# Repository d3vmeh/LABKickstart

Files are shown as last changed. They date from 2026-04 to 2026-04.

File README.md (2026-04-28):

# LABKickstart

> An open, modular, IoT-enabled physics lab toolkit.
> 🥇 **1st place overall — IDEA Hacks 2026**

LABKickstart turns a laptop and a few $10 ESP32 boards into a complete physics
lab data-acquisition system. Each module reads one sensor and broadcasts over
Bluetooth LE; a Python web dashboard receives the streams, runs experiment-
specific derivations, plots live data, writes clean CSVs, and (optionally)
uses an LLM to convert teachers' existing lab handouts into student-facing
setup guides.

**No proprietary base station. No proprietary file format. No vendor lock-in.**

---

## Why

Incumbents have controlled high school physics for years. A $450 base station
before you buy a single sensor; locked connectors; locked file formats. A
district that has spent $30k on one vendor has to keep buying that vendor —
every locked connector is a moat.

A full LABKickstart kit costs less than one typical base station and unlocks
20+ standard physics experiments — Hooke's law, Atwood machines, projectile
motion, free fall, pendulums, collisions, friction, buoyancy.

Every line of firmware, every Python module, every CAD file is open source.
A teacher who has spent twenty years using existing tools can fork an experiment, modify
it for their classroom, and share it with the teacher next door — in twenty
minutes.

---

## Open hardware

All mechanical designs live in OnShape and are publicly viewable:

**🔗 [LABKickstart CAD on OnShape](https://cad.onshape.com/documents/6798fb3b1ef260424d103dd4/w/9adcb538dd3efbe956fa17f1/e/e2a2e2dccae245fef01fc912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)**

Includes the photogate housings, IMU mounts, the ToF stand, and the modular
mounting rail that lets students reconfigure setups between experiments.
Fork the workspace, modify, export STLs, print, run.

Firmware (Arduino sketches per module) lives in [`firmware/`](firmware/).

---

## Architecture

```
┌─────────────────┐  BLE notify   ┌──────────────────┐    WebSocket   ┌──────────────┐
│ ESP32 module(s) │ ────────────> │ Python Hub       │ ─────────────> │ uPlot charts │
│  (one sensor    │   GATT char   │  · BLE manager   │                │ (vanilla JS) │
│   per board)    │               │  · Kit derive    │ ─── CSV ────>  │              │
└─────────────────┘               │  · Run + trigger │                │              │
                                  │  · LLM (teacher) │                │              │
                                  └──────────────────┘                └──────────────┘
```

- **Modules** ([`firmware/`](firmware/)) — Arduino sketches per sensor (photogate, IMU, ToF).
- **BLE manager** (`src/labkickstart/ble_manager.py`) — profile registry,
  auto-discovery of NOTIFY characteristics, per-connection stateful decoders.
- **Hub** (`src/labkickstart/app.py`) — single asyncio event loop. Fans every
  decoded sample to (1) the active run's CSV writer, (2) all WebSocket
  subscribers, and (3) the active kit's `derive()` function, which can emit
  additional physics-quantity samples back into the same fan-out.
- **Kits** (`src/labkickstart/kits.py`) — one Python class per experiment.
  Each declares `info`, `configure(params)`, `derive(sample)`, and the BLE
  modules it requires. Adding an experiment = adding one class.
- **Lab-guide LLM** (`src/labkickstart/lab_guides.py`) — gpt-4o-mini with
  schema-constrained output. Two flows: kit recommender (PDF → ranked kits)
  and student-facing setup guide.
- **Quicklook** (`src/labkickstart/quicklook.py`) — per-channel summary stats
  (count, mean, median, p5, p95, σ, σ/√N) computed from any run's CSV.
- **Frontend** (`src/labkickstart/static/`) — vanilla JS, uPlot, no build
  step. Per-device chart cards keep different sensor scales from crushing
  each other on a shared y-axis.

---

## Quickstart

Runs on macOS or a Raspberry Pi 4 (any host with Bluetooth and Python 3.11+).

```bash
# 1. Clone + install
git clone https://github.com/d3vmeh/LABKickstart
cd LABKickstart
python3 -m venv .venv
.venv/bin/pip install -r requirements.txt

# 2. (optional) AI features
echo "OPENAI_API_KEY=sk-..." > .env

# 3. Launch the dashboard
./dev.sh
# -> open http://localhost:8000
```

`dev.sh` injects `src/` onto `PYTHONPATH` and starts uvicorn with
`--reload`. Override host/port via env:

```bash
HOST=127.0.0.1 PORT=8001 ./dev.sh
```

### No hardware? Use a mock source

Set `LK_SENSOR` before launching to drive the UI from a built-in synthetic
sensor:

```bash
LK_SENSOR=imu       ./dev.sh   # mock IMU
LK_SENSOR=photogate ./dev.sh   # mock photogate
LK_SENSOR=tof       ./dev.sh   # mock ToF
```

---

## Hardware modules

Each module is an ESP32 plus one sensor, battery-powered for months between
charges. Current modules:

| Module | Sensor | Channels |
|---|---|---|
| `IMU_Module` | LSM303 6-axis IMU | `pitch_deg`, `roll_deg`, `accel_x/y/z` |
| `BEAMBREAK_Module` | Dual IR photogate | `gate_A_break_us`, `gate_B_break_us` |
| `TOF_Module` | VL53L0X laser ToF | `distance_mm` |

Adding a new module = one entry in `PROFILES` (`src/labkickstart/ble_manager.py`)
+ one Arduino sketch in `firmware/`.

---

## Built-in kits

| Kit ID | Experiment | Modules required |
|---|---|---|
| `sandbox` | Any sensors, raw passthrough | (any) |
| `photogate` | Two-photogate kinematics | `BEAMBREAK_Module` |
| `imu` | IMU monitor (tilt, free-fall) | `IMU_Module` |
| `imu_sinusoid` | Band-pass smoothed oscillations | `IMU_Module` |
| `tof` | Distance monitor + auto-stop | `TOF_Module` |
| `shm` | SHM with cross-sensor verification  | `TOF_Module`, `IMU_Module` |

### Adding a new kit

```python
class MyKit:
    info = KitInfo(
        id="my_kit",
        name="My Experiment",
        description="...",
        params=[KitParam("foo", "Foo", "m", default=1.0)],
        modules=["IMU_Module"],
    )

    def configure(self, params): ...
    def derive(self, sample) -> Iterable[Sample]: ...
```

Then register it in `build_registry()`. That's the whole framework.

---

## AI features (opt-in)

Both require `OPENAI_API_KEY`. Both use `gpt-4o-mini` with schema-constrained
output. Both cache results to disk. Cost is ~$0.001 per call.

- **Lab-guide generator** — upload a teacher's existing PDF, get a structured
  materials list + numbered student steps, with a "why" sentence per step
  that explains the underlying physics or measurement reason.
- **Kit recommender** — same PDF, GPT picks the best-matching kit from a
  closed enum of registry IDs (cannot hallucinate a kit). Returns rationale,
  confidence, and the physical modules required (server-injected from the
  registry, not LLM-generated).

If the env key is unset, both features return HTTP 503 and the rest of the
dashboard runs unaffected.

---

## API

| Method | Path | Purpose |
|---|---|---|
| GET | `/` | Dashboard |
| GET | `/api/devices` | List connected + scanned devices |
| POST | `/api/ble/scan` | Trigger a BLE scan |
| POST | `/api/ble/connect/{address}` | Connect to a discovered device |
| POST | `/api/ble/disconnect/{address}` | Disconnect |
| GET | `/api/kits` | List kits + active selection |
| POST | `/api/kit` | Apply a kit |
| POST | `/api/kits/recommend` | LLM kit recommender (from PDF) |
| POST | `/api/kits/{id}/lab_guide` | Generate a student lab guide |
| POST | `/api/arm` | Start a run |
| POST | `/api/stop` | Stop the active run |
| GET | `/api/runs` | List runs + active state |
| GET | `/api/runs/{id}/csv` | Download a run's CSV |
| GET | `/api/runs/{id}/quicklook` | Per-channel summary stats |
| WS | `/ws/stream` | Live sample stream |

Every WebSocket message is a JSON object: `{"device_id", "t", "channel", "value"}`,
or `{"type": "run_state", "active": ...}` for run lifecycle events.

---

## Repository layout

```
LABKickstart/
├── firmware/                  # ESP32 Arduino sketches (one per module)
│   ├── device_interfaces/
│   └── photogate_test/
├── src/labkickstart/
│   ├── app.py                 # FastAPI app + Hub (asyncio fan-out)
│   ├── ble_manager.py         # BLE profile registry + connection manager
│   ├── kits.py                # Kit registry (each experiment is a class)
│   ├── lab_guides.py          # LLM: lab-guide generator + kit recommender
│   ├── quicklook.py           # Per-run summary stats
│   ├── runs.py                # Run/CSV lifecycle + auto-stop triggers
│   ├── sensors.py             # Sample dataclass + mock sources
│   └── static/                # Dashboard (HTML + vanilla JS + uPlot)
├── docs/
├── data/                      # Run CSVs (gitignored)
├── dev.sh
├── requirements.txt
└── pyproject.toml
```

---

## Roadmap

- Force, optical, and magnetic-field modules (open-hardware spec, same kit framework)
- Kit marketplace — teachers publish their own Kit classes
- Firmware OTA from the dashboard so teachers don't touch the Arduino IDE
- Classroom pilot, fall 2026

---

## License

- **Software** (everything under `src/`, `firmware/`): Apache License 2.0
- **Hardware designs** (OnShape document linked above + future exports): CERN-OHL-S v2

Apache 2.0 is permissive: you can use, modify, and redistribute the software
freely, including commercially, with an explicit patent grant from contributors.
CERN-OHL-S is the hardware analog of GPL: forks of the CAD can be manufactured
freely, but modified designs that are redistributed must remain open under the
same license — improvements flow back to the community.

See `LICENSE` (Apache 2.0) for software, `LICENSE-HARDWARE` (CERN-OHL-S v2)
for hardware designs.

---

## Acknowledgements

Built at **IDEA Hacks 2026**. Thanks to the organizers, mentors, and every
teacher who has worked around proprietary lab equipment for the past forty
years.

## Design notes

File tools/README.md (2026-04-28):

# tools/

Standalone scripts that don't ship with the dashboard. Useful during
hardware bring-up or debugging.

## `ble_listen.py`

Connect to a LABKickstart ESP32 over BLE and print raw notifications.
Confirms a module is advertising and streaming before you involve the
full server.

```bash
# scan only
python tools/ble_listen.py --scan

# connect + stream by name
python tools/ble_listen.py --name IMU_Module

# connect + stream by address
python tools/ble_listen.py --address AA:BB:CC:DD:EE:FF
```

Auto-discovers the first NOTIFY-able characteristic on the device, so
it works for any module that follows the LABKickstart BLE convention.

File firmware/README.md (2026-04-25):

# LABKickstart firmware

ESP32 sketches for the sensor modules. One folder per module so each one is its
own Arduino sketch.

| Folder | Purpose |
|---|---|
| `photogate_test/` | One IR beam-break wired to one ESP32. Smoke-test for BLE.|
| `device_interfaces/`  | Reference sketches and the project-wide BLE convention.  |

The wire protocol every module follows is documented in
[`device_interfaces/README.md`](device_interfaces/README.md). Read that
before writing a new module.

## Building / flashing

Each folder is a standard Arduino sketch (folder name == `.ino` name).

1. Open the `.ino` file in Arduino IDE 2.x (or `arduino-cli compile`).
2. Boards Manager → install **esp32 by Espressif** (3.x).
3. Select your ESP32 board (e.g. *ESP32 Dev Module* or *DOIT ESP32 DEVKIT V1*).
4. Select the serial port the board enumerates as.
5. Upload.

The BLE stack is the one bundled with the ESP32 Arduino core — no extra
libraries required for the photogate module. The IMU example sketch needs
the **Adafruit LSM303 Accel** + **Adafruit Unified Sensor** libraries from
the Library Manager.

## On-air protocol (one-line summary)

- Device name: `LK-<Module>-<id>` (e.g. `LK-Photogate-A`)
- Service UUID: `5b1e0001-9e8d-4f3a-b50f-1a2b3c4d5e6f`
- Events char:  `5b1e0002-9e8d-4f3a-b50f-1a2b3c4d5e6f` (notify)
- Each notification: `{"channel":"<name>","value":<number>}`

Full spec, channel naming rules, cadence guidance:
[`device_interfaces/README.md`](device_interfaces/README.md).

## Smoke-testing from any computer with BLE

A small CLI listener lives at `tools/ble_listen.py`.

```bash
pip install bleak
python tools/ble_listen.py --scan          # list LK-* devices in range
python tools/ble_listen.py                 # connect to LK-Photogate-A and stream
python tools/ble_listen.py --name LK-IMU-01
```

You should see one line per event:

```
[13:42:07] #1    gate_A_break_us=58231
[13:42:09] #2    pitch_deg=37.4
```

If `--scan` finds nothing: check the ESP32 has booted (serial monitor) and
that BLE isn't disabled on the host.

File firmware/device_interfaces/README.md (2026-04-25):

# LABKickstart device convention

Every BLE-connected sensor module in this project advertises the same way and
emits events with the same shape. That's what lets the Pi treat them
uniformly: one BLE client, one parser, and the kit/Sample model on the server
side never has to know what hardware produced an event.

If you're writing a new module, follow this spec.

## Device name

`LK-<ModuleType>-<id>`

| Example | Meaning |
|---|---|
| `LK-Photogate-A` | First photogate module (gate A) |
| `LK-Photogate-B` | Second photogate module (gate B) |
| `LK-IMU-01` | First IMU module |
| `LK-LoadCell-01` | First load-cell module |

The Pi-side scanner uses the `LK-` prefix to find LABKickstart modules and
ignore everything else on the air.

## BLE service & characteristic

One service, one events characteristic. Same UUIDs on every module.

```
Service UUID         5b1e0001-9e8d-4f3a-b50f-1a2b3c4d5e6f
Events char UUID     5b1e0002-9e8d-4f3a-b50f-1a2b3c4d5e6f
                     properties: NOTIFY (required) + READ (optional)
                     descriptor: BLE2902 (CCCD) so the Pi can subscribe
```

Do not invent new UUIDs per module. If you need to publish multiple values,
emit multiple events on the same characteristic.

## Event payload

Each BLE notification is one UTF-8 JSON object on its own.

Required fields:

| Field | Type | Notes |
|---|---|---|
| `channel` | string | snake_case identifier, units in the name (`break_us`, `pitch_deg`, `force_n`) |
| `value` | number | the measurement |

Optional extras: any other fields the module wants to attach (sequence
numbers, raw counters, calibration flags, etc.). The Pi-side parser maps
`channel` and `value` directly onto a `Sample`; extras are preserved in the
event stream but ignored by the kits unless they explicitly look for them.

```json
{"channel":"gate_A_break_us","value":59917}
{"channel":"pitch_deg","value":59.05}
{"channel":"force_n","value":12.4,"raw_counts":83214}
```

Channel names are stable, lowercase, snake_case, and self-describing. They
should include units (e.g. `_us`, `_n`, `_deg`, `_mps`). The kits and CSVs
on the Pi key off these names.

## Cadence

- **Event-driven sensors** (photogate, button, switch): emit one notification
  per real event. Don't synthesize a continuous stream.
- **Continuous sensors** (IMU, load cell, thermistor): emit at a fixed rate.
  Cap at **100 Hz per channel** unless you have a specific reason to go
  higher. The BLE GATT layer can keep up, but slow centrals (laptops,
  phones) start dropping packets above that.

## Connection lifecycle

- Implement `BLEServerCallbacks::onDisconnect` and call
  `BLEDevice::startAdvertising()` from it. Without this, the module stops
  being reachable after the first disconnect.
- Buffer at most one in-flight event in your firmware. If notifications back
  up because the central isn't reading, drop new events rather than queuing
  them — the data is realtime.

## Reference sketches

| Folder | Pattern |
|---|---|
| `../photogate_test/` | Event-driven (ISR) + JSON events. Canonical example. |
| `esp32_BLE_Server_Data_Output/` | Continuous sensor at 50 Hz + JSON events. Replace stub with real sensor read. |
| `esp32_beamBreak/` | How to read an IR break-beam. No BLE. |
| `esp32_accel_degrees/` | How to read the LSM303 + compute pitch/roll. No BLE. |
| `esp32_find_MAC_address/` | Utility to identify boards. |

The `esp32_*` folders without BLE are scratch/learning sketches. The shipping
modules live next to `photogate_test/`.

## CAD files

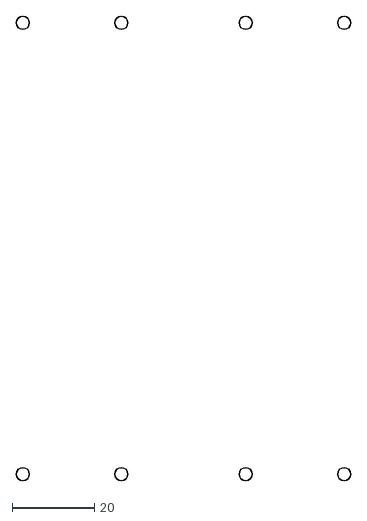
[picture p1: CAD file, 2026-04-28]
Hardware DXFs/IMU Mounting.dxf
81.5 x 113.2

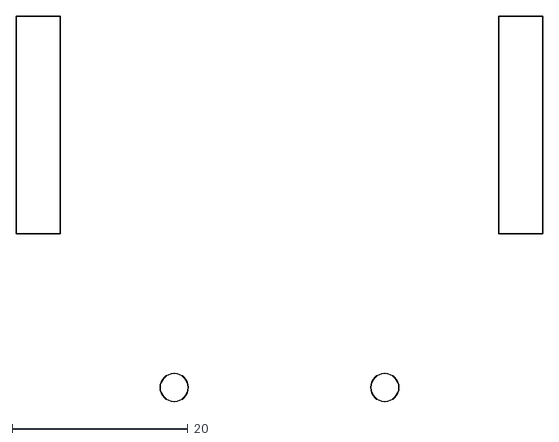
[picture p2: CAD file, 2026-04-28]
Hardware DXFs/ToF Sensor Mounting 0.188in.dxf
60.0 x 43.9

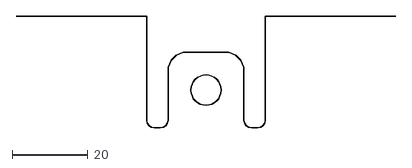
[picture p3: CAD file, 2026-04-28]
Hardware DXFs/Photogate Mounting 0.22in.dxf
100.0 x 29.5

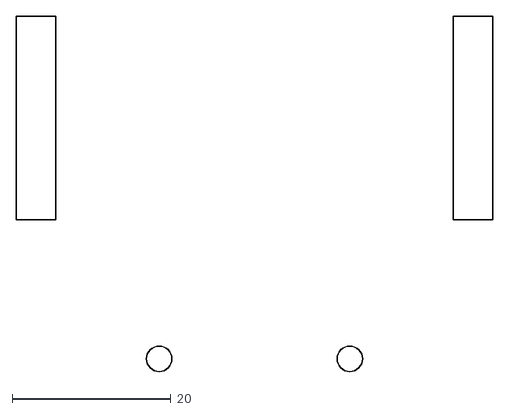
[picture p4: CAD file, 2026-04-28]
Hardware DXFs/ToF Sensor Mounting 0.22in.dxf
60.0 x 44.7

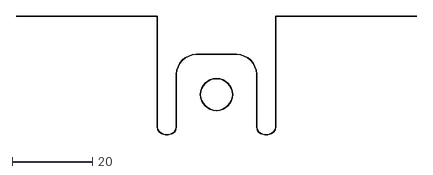
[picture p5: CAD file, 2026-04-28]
Hardware DXFs/Photogate Mounting 0.188in.dxf
100.0 x 29.5

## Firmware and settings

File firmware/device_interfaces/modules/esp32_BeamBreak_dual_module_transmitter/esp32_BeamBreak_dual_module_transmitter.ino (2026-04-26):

/* for BLE transmission   */
#include <BLEDevice.h>
#include <BLEServer.h>
#include <BLE2902.h>

#define SERVICE_UUID        "a13ebb02-0bce-4cab-a875-2659399c1da3"
#define BEAMBREAK_UUID      "c650e0f7-e67d-46cf-ba89-4fd287070199"

#define BLE_DEVICE_NAME   "BEAMBREAK_Module_2"

BLECharacteristic* pBeamCharacteristic;

// Separate LED Pins
#define LED_A_PIN 23
#define LED_B_PIN 25

#define BLOCKED_LEVEL LOW 
#define DEBOUNCE_US 10000 

// Separate Sensor Pins
const int PIN_A = 18; 
const int PIN_B = 19;

// Separate IDs for the data packet
const uint8_t ID_A = 1;
const uint8_t ID_B = 2;

struct __attribute__((packed)) BeamBreakData {
  uint8_t gate_id;
  uint8_t state; 
};

// Tracking for Sensor A
int lastStateA = -1;
unsigned long lastTimeA = 0;

// Tracking for Sensor B
int lastStateB = -1;
unsigned long lastTimeB = 0;

class ServerCallbacks : public BLEServerCallbacks {
  void onDisconnect(BLEServer*) override {
    BLEDevice::startAdvertising();
  }
};

void setup() {
  // Serial.begin(115200);
  delay(1000);

  // Setup LEDs
  pinMode(LED_A_PIN, OUTPUT);
  pinMode(LED_B_PIN, OUTPUT);
  
  // Setup Sensors
  pinMode(PIN_A, INPUT_PULLUP);
  pinMode(PIN_B, INPUT_PULLUP);

  lastStateA = digitalRead(PIN_A);
  lastStateB = digitalRead(PIN_B);

  BLEDevice::init(BLE_DEVICE_NAME);
  BLEServer* pServer = BLEDevice::createServer();
  pServer->setCallbacks(new ServerCallbacks());   
  BLEService* pService = pServer->createService(SERVICE_UUID);

  pBeamCharacteristic = pService->createCharacteristic(
    BEAMBREAK_UUID,
    BLECharacteristic::PROPERTY_NOTIFY
  );

  pBeamCharacteristic->addDescriptor(new BLE2902());
  pService->start();
  pServer->getAdvertising()->start();
}

void loop() {
  unsigned long now = micros();

  // Read both sensors
  int rawA = digitalRead(PIN_A);
  int rawB = digitalRead(PIN_B);

  // --- LED LOGIC ---
  // LED A follows Sensor A
  if (rawA == BLOCKED_LEVEL) {
    digitalWrite(LED_A_PIN, HIGH);
  } else {
    digitalWrite(LED_A_PIN, LOW);
  }

  // LED B follows Sensor B
  if (rawB == BLOCKED_LEVEL) {
    digitalWrite(LED_B_PIN, HIGH);
  } else {
    digitalWrite(LED_B_PIN, LOW);
  }

  // --- Handle Sensor A BLE ---
  if (rawA != lastStateA) {
    if (now - lastTimeA >= DEBOUNCE_US) {
      BeamBreakData data;
      data.gate_id = ID_A;
      data.state = (rawA == BLOCKED_LEVEL) ? 1 : 0;

      pBeamCharacteristic->setValue((uint8_t*)&data, sizeof(data));
      pBeamCharacteristic->notify();

      lastStateA = rawA;
      lastTimeA = now;
    }
  }

  // --- Handle Sensor B BLE ---
  if (rawB != lastStateB) {
    if (now - lastTimeB >= DEBOUNCE_US) {
      BeamBreakData data;
      data.gate_id = ID_B;
      data.state = (rawB == BLOCKED_LEVEL) ? 1 : 0;

      pBeamCharacteristic->setValue((uint8_t*)&data, sizeof(data));
      pBeamCharacteristic->notify();

      lastStateB = rawB;
      lastTimeB = now;
    }
  }

  // delay(1);
}

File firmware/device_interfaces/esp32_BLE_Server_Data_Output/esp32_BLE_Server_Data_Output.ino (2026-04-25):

// LABKickstart - Reference BLE module
// Demonstrates the project-wide convention so future modules (load cell,
// IMU, etc.) all look the same to the Pi:
//
//   - Device name: "LK-<Module>-<id>"
//   - Shared service UUID + single events characteristic (notify)
//   - Each notification is one UTF-8 JSON object: {"channel": "...", "value": N}
//   - Notify on real events, or rate-limit continuous sensors (~50 Hz max)
//   - Re-start advertising on disconnect so the Pi can reconnect
//
// This sketch fakes a pitch reading; replace the value with a real sensor
// read (LSM303, MPU6050, etc.) when you copy it.
//
// Spec: firmware/device_interfaces/README.md

#include <Arduino.h>
#include <BLEDevice.h>
#include <BLEServer.h>
#include <BLEUtils.h>
#include <BLE2902.h>

// ---------- Project-wide UUIDs (do NOT change for new modules) ----------
#define SERVICE_UUID     "5b1e0001-9e8d-4f3a-b50f-1a2b3c4d5e6f"
#define EVENTS_CHAR_UUID "5b1e0002-9e8d-4f3a-b50f-1a2b3c4d5e6f"

// ---------- Per-module configuration ----------
static const char*    DEVICE_NAME       = "LK-IMU-01";
static const char*    PITCH_CHANNEL     = "pitch_deg";
static const uint32_t SAMPLE_PERIOD_MS  = 20;   // 50 Hz

// ---------- State ----------
BLECharacteristic* eventsChar = nullptr;
volatile bool      deviceConnected = false;

class ServerCallbacks : public BLEServerCallbacks {
  void onConnect(BLEServer*) override {
    deviceConnected = true;
    Serial.println("[BLE] central connected");
  }
  void onDisconnect(BLEServer*) override {
    deviceConnected = false;
    Serial.println("[BLE] central disconnected, re-advertising");
    BLEDevice::startAdvertising();
  }
};

void publishEvent(const char* channel, double value) {
  char payload[96];
  int n = snprintf(payload, sizeof(payload),
                   "{\"channel\":\"%s\",\"value\":%.4f}", channel, value);
  if (n <= 0) return;
  Serial.println(payload);
  if (deviceConnected && eventsChar) {
    eventsChar->setValue((uint8_t*)payload, (size_t)n);
    eventsChar->notify();
  }
}

void setup() {
  Serial.begin(115200);
  delay(200);
  Serial.print("[boot] LABKickstart module ");
  Serial.println(DEVICE_NAME);

  BLEDevice::init(DEVICE_NAME);
  BLEServer* server = BLEDevice::createServer();
  server->setCallbacks(new ServerCallbacks());

  BLEService* svc = server->createService(SERVICE_UUID);
  eventsChar = svc->createCharacteristic(
      EVENTS_CHAR_UUID,
      BLECharacteristic::PROPERTY_READ | BLECharacteristic::PROPERTY_NOTIFY);
  eventsChar->addDescriptor(new BLE2902());
  svc->start();

  BLEAdvertising* adv = BLEDevice::getAdvertising();
  adv->addServiceUUID(SERVICE_UUID);
  adv->setScanResponse(true);
  adv->setMinPreferred(0x06);
  BLEDevice::startAdvertising();

  Serial.print("[BLE] advertising as ");
  Serial.println(DEVICE_NAME);
}

void loop() {
  // Replace this stub with a real sensor read.
  static double fakePitch = 0;
  fakePitch += 0.5;
  if (fakePitch > 90) fakePitch = -90;

  publishEvent(PITCH_CHANNEL, fakePitch);

  delay(SAMPLE_PERIOD_MS);
}

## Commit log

2026-04-25 added esp32 code for IMU module
2026-04-25 deleted unnecessary i2c register write function
2026-04-25 added LED to beam break example
2026-04-26 removed print statements from module 1 and 2, and also created dual module transmitter program
2026-04-27 Rewrite README for v1: open-source positioning, OnShape CAD link, full architecture
    Replaces the v0 stub with a public-facing README that pitches LABKickstart's
    open-source story (CAD on OnShape, no proprietary base station, kit
    framework), documents every shipped module/kit/route, and frames the
    licensing split (Apache 2.0 software, CERN-OHL-S v2 hardware).
2026-04-27 Error handling, sample drop, correctness fixes
2026-04-28 added drawings for each flatpack module
    [IMU Mounting.dxf, Photogate Mounting 0.188in.dxf, Photogate Mounting 0.22in.dxf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]
2026-04-28 Moving dxfs
    [Photogate Mounting 0.188in.dxf, Photogate Mounting 0.22in.dxf, ToF Sensor Mounting 0.188in.dxf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]
